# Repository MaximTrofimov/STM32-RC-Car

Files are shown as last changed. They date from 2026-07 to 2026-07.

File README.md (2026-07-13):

# STM32-RC-Car
RC car with manual and autonomous modes, dual STM32 wireless communication (remote and car PCBs).

## Demo Videos

**Manual Mode**

manual

**Autonomous Mode**

autonomous

## Photos

**RC Car and Remote**



**Remote and Car PCBs**



## Overview
- Designed two custom PCBs (remote and car) for a wirelessly-controlled RC car
- Implemented wireless communication between two STM32 microcontrollers using embedded firmware (HAL library)
- Developed manual and autonomous modes

## Hardware
- STM32F446RE (x2 - one in car, one in remote)
- NucleoF446RE (x2 - prototyping)
- NRF24L01+PA+LNA wireless transceiver modules (x2 - one for car, one for remote)
- HC-SR04 ultrasonic sensor (x3 - front, left, right)
- SG90 servo motor (steering)
- TB6612FNG dual H-bridge motor driver (RWD)
- TT dual DC motor 3-6V (x2)
- KY-023 dual-axis analog joystick (remote)
- Custom PCBs (x2 - one for car, one for remote)
- 2S Lipo battery (car)
- 1s Li Ion battery (remote)

## Repo Structure
```
Firmware/
  car_mcu/       - STM32 embedded firmware for the car MCU
  remote_mcu/    - STM32 embedded firmware for the remote MCU
Hardware/
  car_pcb/       - Car PCB, schematic, BOM
  remote_pcb/    - Remote PCB, schematic, BOM
Mechanical/       - Wheels and steering servo enclosure CAD files (STEP)
```

## How It Works

**Manual Mode:**
The X and Y coordinates of the joystick position are read into a two variable array, VR. The array is then transmitted alongside each packet using the remote PCB's NRF24L01 module, and received at the car PCB's NRF24L01 module. The DC Motors are controlled using the TB6612FNG where a maximum joystick value results in fully duty cycle, a neutral results in zero duty cycle, and a minimum results in maximum duty cycle spinning the motors the other way. The SG90 steering is controlled via a timer for PWM. If the joystick is extended to the far right or far left, the NRF24L01 sends a larger joystick value and therefore the pulse is set to high for longer. Both throttle and steering respond to the specific displacement of the joystick from its absolute center, giving it the ability to control speed, and steering degree. The firmware dictates what part of the packet is responsible for motors, what part for the steering angle, and what part for the mode, which is triggered via an interrupt. 

**Autonomous Mode:**
If the joystick button is pressed, the mode is toggled to autonomous. Motors begin by running on half duty cycle and steering is set to a constant of about 20 degrees. The front, left, and right ultrasonic sensors notify the microcontroller when an obstacle is a certain distance away. Once this happens the car stops, checks its sides, goes back, and turns to the side where there is more free space. 

## Firmware Configuration

**Car MCU**
<p float="left">
  
  
</p>

**Remote MCU**
<p float="left">
  
  
</p>

## PCB Design

**Car PCB**
<p float="left">
  
  
</p>

**Remote PCB**
<p float="left">
  
  
</p>

## Breadboard Prototyping

  

## Power

**Car PCB**
- 2S Lipo -> 3.3V (500 mA rating, STM32, NRF24L01, TB6612FNG logic): TPS62152RGTR, reference schematic on Texas Instruments Power Designer.
- 2S Lipo -> 5V (2A rating, TB6612FNG motor power, SG90, HCSR04): TPS82130SILR, reference schematic on Texas Instruments Power Designer.

**Remote PCB**
- 1S Li-Ion -> 3.3V (600 mA rating, STM32, KY-023, NRF24L01): AP2112K-3.3TRG1, reference schematic on datasheet. Used LDO due to lower voltage difference. 

## Credits
- Shawn Hymel STM32 Tutorial Series [https://www.youtube.com/watch?v=hyZS2p1tW-g&list=PLEBQazB0HUyRYuzfi4clXsKUSgorErmBv]
- Phil's Lab KiCad Tutorial [https://www.youtube.com/watch?v=aVUqaB0IMh4]
- NRF24L01 Tutorial Series [https://www.youtube.com/watch?v=mB7LsiscM78&t=996s]
- HCSR04 Tutorial Article [https://controllerstech.com/hcsr04-ultrasonic-sensor-and-stm32/]
- SG90 Tutorial Article [https://controllerstech.com/servo-motor-with-stm32/]
- TB6612FNG Tutorial Video [https://www.youtube.com/watch?v=zWYYvtU8Wt4]
- Joystick Module Tutorial Article [https://controllerstech.com/joystick-and-stm32/]
- Texas Instruments 2S Lipo -> 3.3V Buck Converter Circuit [https://webench.ti.com/power-designer/switching-regulator/customize/5?noparams=0]
- Texas Instruments 2S Lipo -> 5V Buck Converter Circuit [https://webench.ti.com/power-designer/switching-regulator/customize/6?noparams=0]

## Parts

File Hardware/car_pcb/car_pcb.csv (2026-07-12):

Designator | Qty | Comment | DNP | Exclude from BOM | Exclude from Board | Footprint | Datasheet | LCSC Part #
C1,C2,C3,C4,C5,C9,C11,C12,C15 | 9 | 100n |  |  |  | Capacitor_SMD:C_0805_2012Metric |  | C49678
C6,C14,C18,C21,C24 | 5 | 10u |  |  |  | Capacitor_SMD:C_0805_2012Metric |  | C15850
C7 | 1 | 10n |  |  |  | Capacitor_SMD:C_0805_2012Metric |  | C1710
C8 | 1 | 1u |  |  |  | Capacitor_SMD:C_0805_2012Metric |  | C28323
C10 | 1 | 4.7u |  |  |  | Capacitor_SMD:C_0805_2012Metric |  | C1779
C19 | 1 | 390p |  |  |  | Capacitor_SMD:C_0805_2012Metric |  | C1741
C20 | 1 | 22u |  |  |  | Capacitor_SMD:C_0805_2012Metric |  | C45783
C22 | 1 | 430p |  |  |  | Capacitor_SMD:C_0805_2012Metric |  | C67898
L1 | 1 | 2.2u |  |  |  | VLS3012CX-2R2M-1:IND_VLS3012CX-2R2M-1 |  | C2683174
R1 | 1 | 10k |  |  |  | Resistor_SMD:R_0805_2012Metric |  | C176201
R2,R4,R6 | 3 | 1k |  |  |  | Resistor_SMD:R_0805_2012Metric |  | C17513
R3,R5,R7 | 3 | 2k |  |  |  | Resistor_SMD:R_0805_2012Metric |  | C17604
R8,R9,R11 | 3 | 100k |  |  |  | Resistor_SMD:R_0805_2012Metric |  | C25611
R10 | 1 | 523k |  |  |  | Resistor_SMD:R_0805_2012Metric |  | C17742
U1 | 1 | STM32F446RET6 |  |  |  | Package_QFP:LQFP-64_10x10mm_P0.5mm | https://www.st.com/resource/en/datasheet/stm32f446re.pdf | C69336
U2 | 1 | TPS62152 3.3V |  |  |  | Package_DFN_QFN:VQFN-16-1EP_3x3mm_P0.5mm_EP1.68x1.68mm_ThermalVias | http://www.ti.com/lit/ds/symlink/TPS62150.pdf | C2070611
U3 | 1 | TPS82130 5V |  |  |  | Package_LGA:Texas_SIL0008D_MicroSiP-8-1EP_2.8x3mm_P0.65mm_EP1.1x1.9mm_ThermalVias | http://www.ti.com/lit/ds/symlink/tps82130.pdf | C473914

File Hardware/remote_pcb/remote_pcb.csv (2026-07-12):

Reference | Qty | Value | DNP | Exclude from BOM | Exclude from Board | Footprint | Datasheet | LCSC
C1 | 1 | 10u |  |  |  | Capacitor_SMD:C_0805_2012Metric |  | C15850
C2,C3,C4,C5,C6,C9,C13 | 7 | 100n |  |  |  | Capacitor_SMD:C_0805_2012Metric |  | C49678
C7 | 1 | 10n |  |  |  | Capacitor_SMD:C_0805_2012Metric |  | C1710
C8,C11,C12,C15 | 4 | 1u |  |  |  | Capacitor_SMD:C_0805_2012Metric |  | C28323
C10 | 1 | 4.7u |  |  |  | Capacitor_SMD:C_0805_2012Metric |  | C1779
FB1 | 1 | 120R |  |  |  | Inductor_SMD:L_0805_2012Metric |  | C79382
R1,R2 | 2 | 10k |  |  |  | Resistor_SMD:R_0805_2012Metric |  | C176201
U1 | 1 | STM32F446RET6 |  |  |  | Package_QFP:LQFP-64_10x10mm_P0.5mm | https://www.st.com/resource/en/datasheet/stm32f446re.pdf | C69336
U2 | 1 | AP2112K-3.3 |  |  |  | Package_TO_SOT_SMD:SOT-23-5 | https://www.diodes.com/assets/Datasheets/AP2112.pdf | C51118

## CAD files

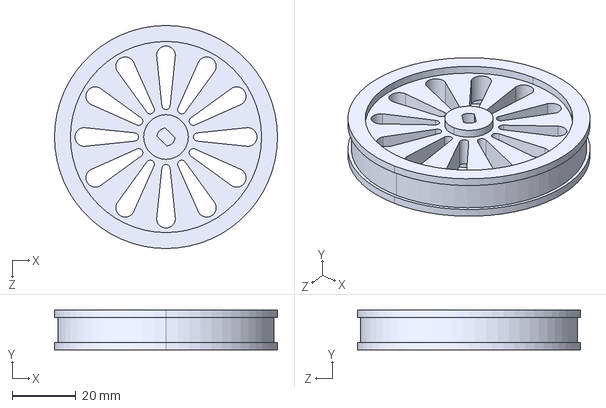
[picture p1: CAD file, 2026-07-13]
Mechanical/RC_Car_Wheel_Rear.STEP
70.0 x 12.5 x 70.0 mm

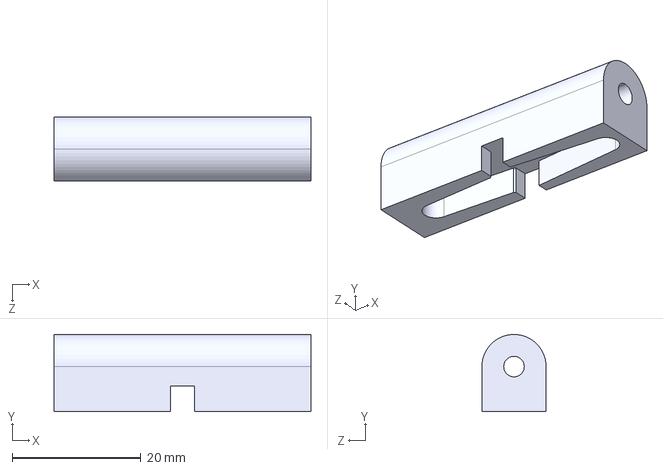
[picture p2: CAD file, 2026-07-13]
Mechanical/Servo_Blade_Enclosure.STEP
40.0 x 12.0 x 10.0 mm

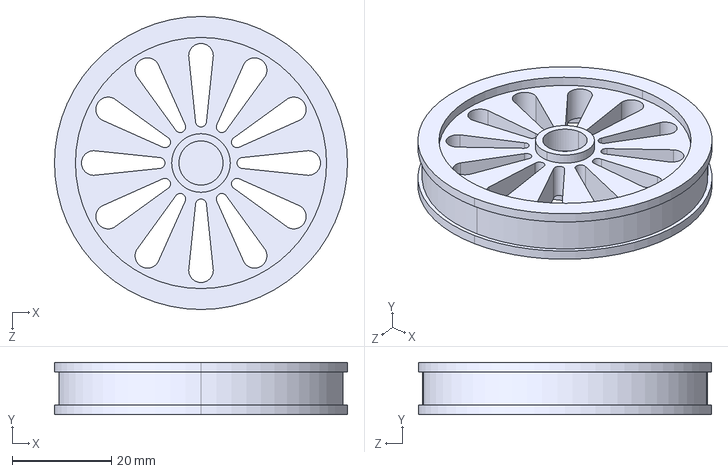
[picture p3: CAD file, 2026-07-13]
Mechanical/RC_Car_Wheel_Front_8.9d.STEP
59.0 x 10.5 x 59.0 mm

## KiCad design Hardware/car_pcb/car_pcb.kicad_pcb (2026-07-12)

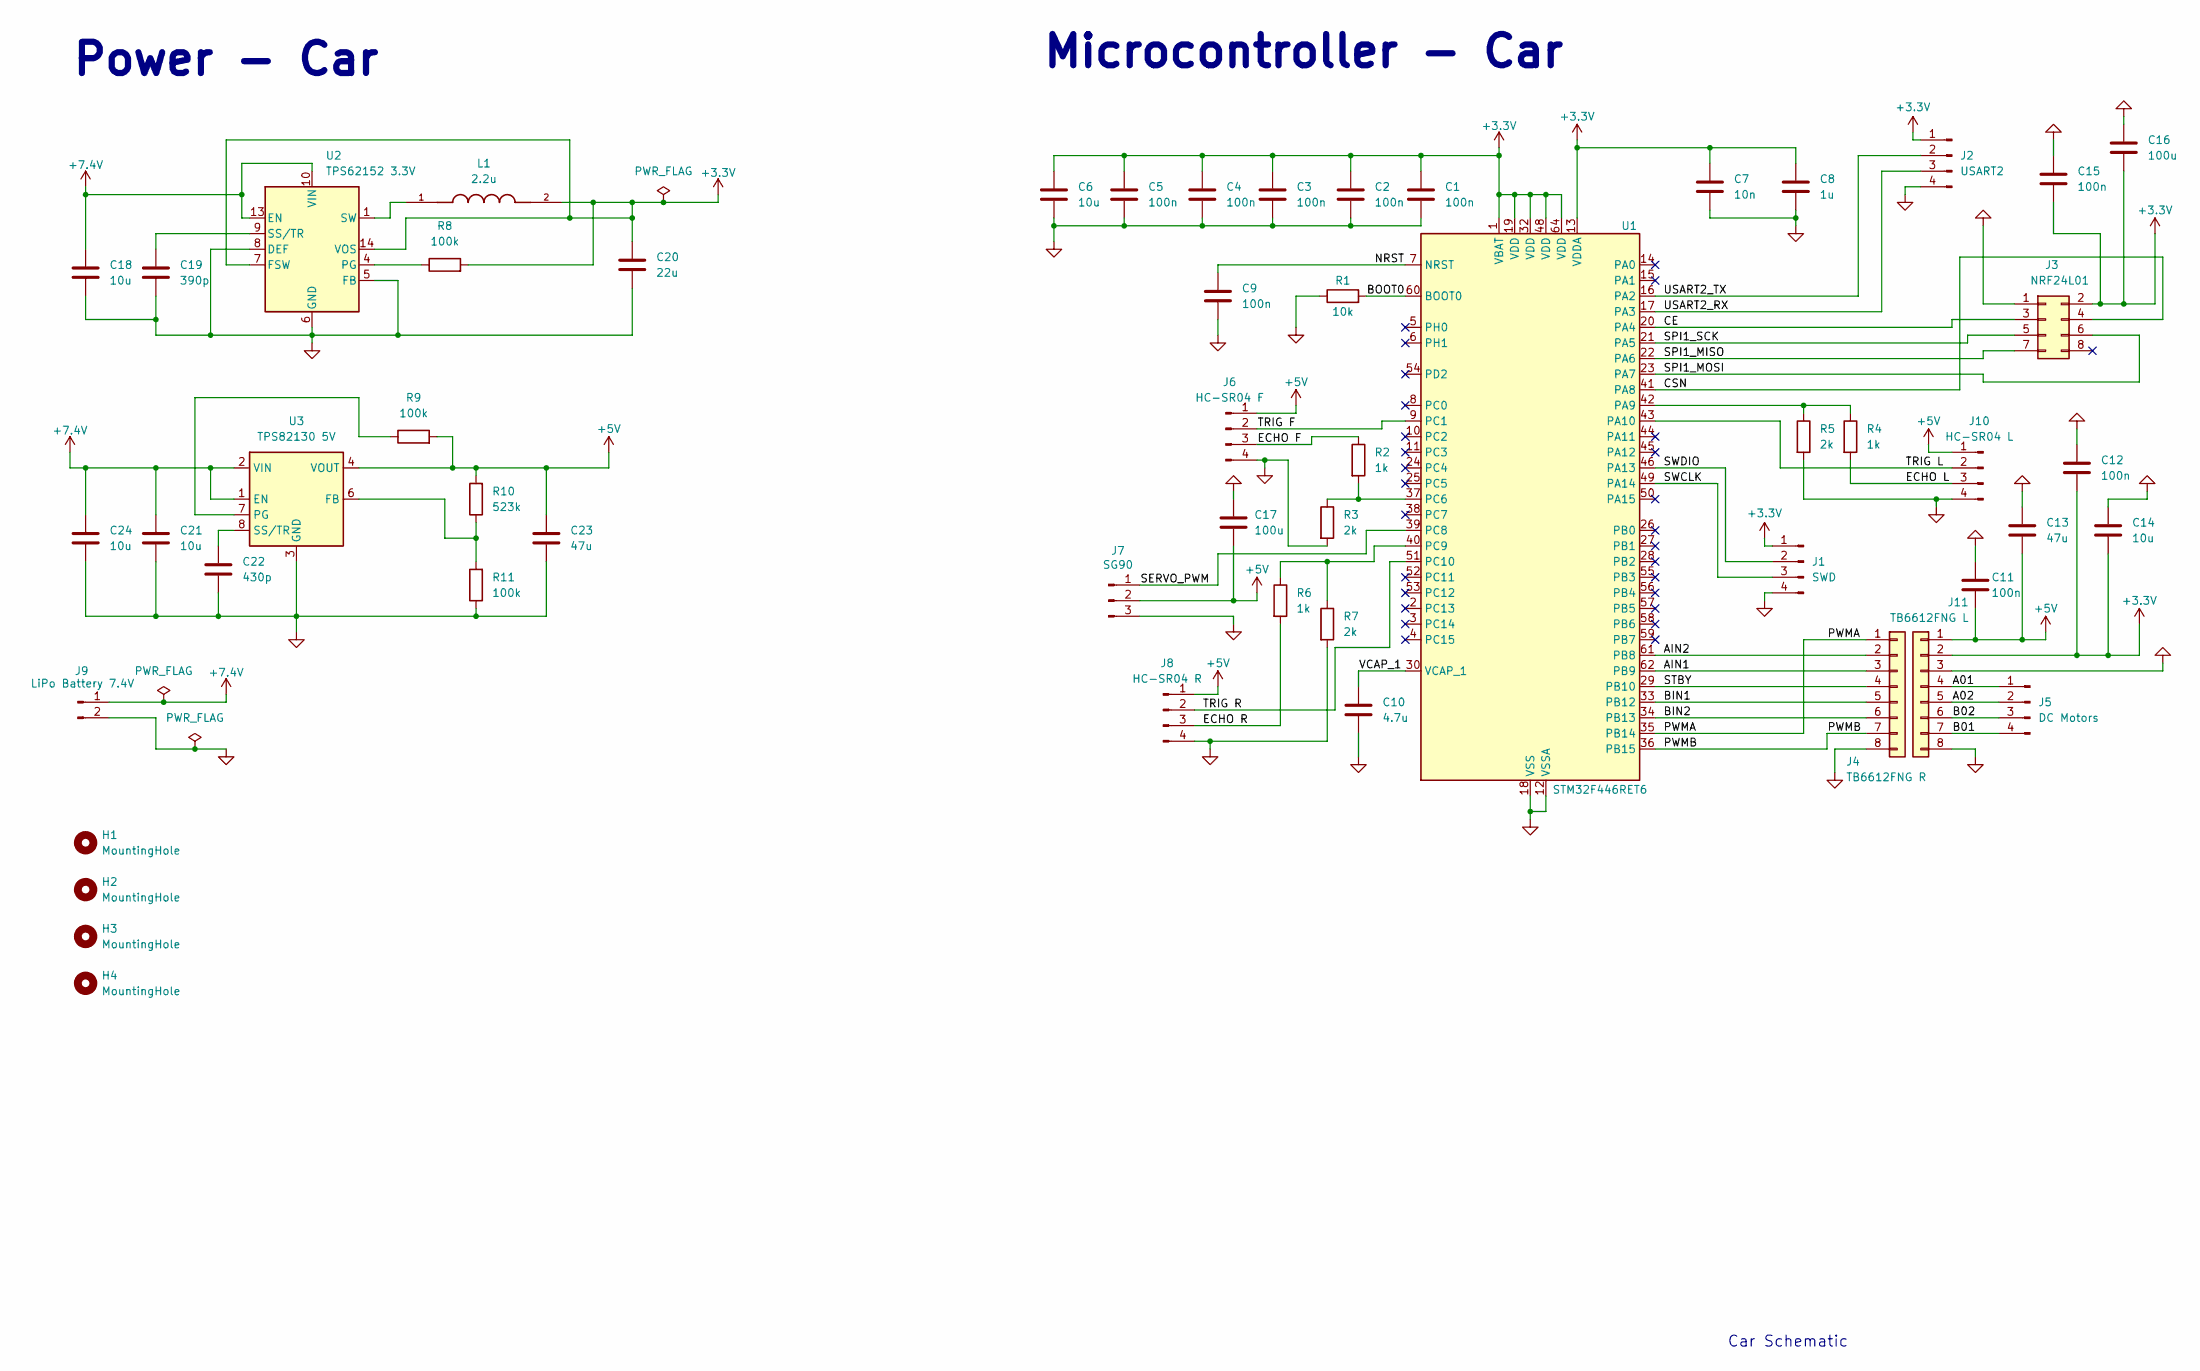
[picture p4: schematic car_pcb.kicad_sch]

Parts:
C1, C2, C3, C4, C5, C9, C11, C12, C15: 100n; C_0805_2012Metric; LCSC C49678
C6, C14, C18, C21, C24: 10u; C_0805_2012Metric; LCSC C15850
C7: 10n; C_0805_2012Metric; LCSC C1710
C8: 1u; C_0805_2012Metric; LCSC C28323
C10: 4.7u; C_0805_2012Metric; LCSC C1779
C13, C23: 47u; C_Radial_D5.0mm_H11.0mm_P2.00mm
C16, C17: 100u; C_Radial_D5.0mm_H11.0mm_P2.00mm
C19: 390p; C_0805_2012Metric; LCSC C1741
C20: 22u; C_0805_2012Metric; LCSC C45783
C22: 430p; C_0805_2012Metric; LCSC C67898
H1, H2, H3, H4: MountingHole; MountingHole_2.2mm_M2
J1: SWD; PinHeader_1x04_P2.54mm_Vertical
J2: USART2; PinHeader_1x04_P2.54mm_Vertical
J3: NRF24L01; PinHeader_2x04_P2.54mm_Vertical
J4: TB6612FNG R; PinHeader_1x08_P2.54mm_Vertical
J5: DC Motors; PinHeader_1x04_P2.54mm_Vertical
J6: HC-SR04 F; PinHeader_1x04_P2.54mm_Vertical
J7: SG90; PinHeader_1x03_P2.54mm_Vertical
J8: HC-SR04 R; PinHeader_1x04_P2.54mm_Vertical
J9: LiPo Battery 7.4V; PinHeader_1x02_P2.54mm_Vertical
J10: HC-SR04 L; PinHeader_1x04_P2.54mm_Vertical
J11: TB6612FNG L; PinHeader_1x08_P2.54mm_Vertical
L1: 2.2u; IND_VLS3012CX-2R2M-1; PARTREV N/A; DigiKey_Part_Number 445-180922-1-ND
R1: 10k; R_0805_2012Metric; LCSC C176201
R2, R4, R6: 1k; R_0805_2012Metric; LCSC C17513
R3, R5, R7: 2k; R_0805_2012Metric; LCSC C17604
R8, R9, R11: 100k; R_0805_2012Metric; LCSC C25611
R10: 523k; R_0805_2012Metric; LCSC C17742
U1: STM32F446RET6; LQFP-64_10x10mm_P0.5mm; LCSC C69336
U2: TPS62152 3.3V; VQFN-16-1EP_3x3mm_P0.5mm_EP1.68x1.68mm_ThermalVias; LCSC C2070611
U3: TPS82130 5V; Texas_SIL0008D_MicroSiP-8-1EP_2.8x3mm_P0.65mm_EP1.1x1.9mm_T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; LCSC C473914

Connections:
+3.3V: C1.1, C2.1, C3.1, C4.1, C5.1, C6.1, C7.1, C8.1, C12.2, C14.2, C15.2, C16.2, C20.1, J1.1, J2.1, J3.2, J11.2, L1.2, R8.2, U1.1 (VBAT), U1.13 (VDDA), U1.19 (VDD), U1.32 (VDD), U1.48 (VDD), U1.64 (VDD), U2.7 (FSW), U2.14 (VOS); also elsewhere on the board
+5V: C11.2, C13.2, C17.2, C23.1, J6.1, J7.2, J8.1, J10.1, J11.1, R9.2, R10.2, U3.4 (VOUT), U3.5 (VOUT); also elsewhere on the board
+7.4V: C18.1, C21.1, C24.1, J9.1, U2.10 (VIN), U2.11 (VIN), U2.12 (VIN), U2.13 (EN), U3.1 (EN), U3.2 (VIN)
/A01: J5.1, J11.4; also elsewhere on the board
/A02: J5.2, J11.5; also elsewhere on the board
/AIN1: J4.3, U1.62 (PB9)
/AIN2: J4.2, U1.61 (PB8)
/B01: J5.4, J11.7; also elsewhere on the board
/B02: J5.3, J11.6; also elsewhere on the board
/BIN1: J4.5, U1.33 (PB12)
/BIN2: J4.6, U1.34 (PB13)
/BOOT0: R1.2, U1.60 (BOOT0)
/CE: J3.3, U1.20 (PA4)
/CSN: J3.4, U1.41 (PA8)
/ECHO F: J6.3, R2.1
/ECHO L: J10.3, R4.2; also elsewhere on the board
/ECHO R: J8.3, R6.2; also elsewhere on the board
/NRST: C9.1, U1.7 (NRST)
/PWMA: J4.1, U1.35 (PB14)
/PWMB: J4.7, U1.36 (PB15)
/SERVO_PWM: J7.1, U1.39 (PC8)
/SPI1_MISO: J3.7, U1.22 (PA6)
/SPI1_MOSI: J3.6, U1.23 (PA7)
/SPI1_SCK: J3.5, U1.21 (PA5)
/STBY: J4.4, U1.29 (PB10)
/SWCLK: J1.3, U1.49 (PA14)
/SWDIO: J1.2, U1.46 (PA13)
/TRIG F: J6.2, U1.9 (PC1)
/TRIG L: J10.2, U1.43 (PA10); also elsewhere on the board
/TRIG R: J8.2, U1.51 (PC10); also elsewhere on the board
/USART2_RX: J2.3, U1.17 (PA3)
/USART2_TX: J2.2, U1.16 (PA2)
/VCAP_1: C10.1, U1.30 (VCAP_1)
GND: C1.2, C2.2, C3.2, C4.2, C5.2, C6.2, C7.2, C8.2, C9.2, C10.2, C11.1, C12.1, C13.1, C14.1, C15.1, C16.1, C17.1, C18.2, C19.2, C20.2, C21.2, C22.2, C23.2, C24.2, J1.4, J2.4, J3.1, J4.8, J6.4, J7.3, J8.4, J9.2, J10.4, J11.3, J11.8, R1.1, R3.2, R5.2, R7.2, R11.1, U1.12 (VSSA), U1.18 (VSS), U1.31 (VSS), U1.47 (VSS), U1.63 (VSS), U2.5 (FB), U2.6 (GND), U2.8 (DEF), U2.15 (GND), U2.16 (GND), U2.17 (GND), U3.3 (GND), U3.9 (GND); also elsewhere on the board
unnamed: L1.1, U2.1 (SW), U2.2 (SW), U2.3 (SW)
unnamed: R4.1, R5.1, U1.42 (PA9)
unnamed: R2.2, R3.1, U1.37 (PC6)
unnamed: R6.1, R7.1, U1.40 (PC9)
unnamed: R8.1, U2.4 (PG)
unnamed: C19.1, U2.9 (SS/TR)
unnamed: R10.1, R11.2, U3.6 (FB)
unnamed: R9.1, U3.7 (PG)
unnamed: C22.1, U3.8 (SS/TR)

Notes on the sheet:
Microcontroller - Car
Car Schematic
Power - Car

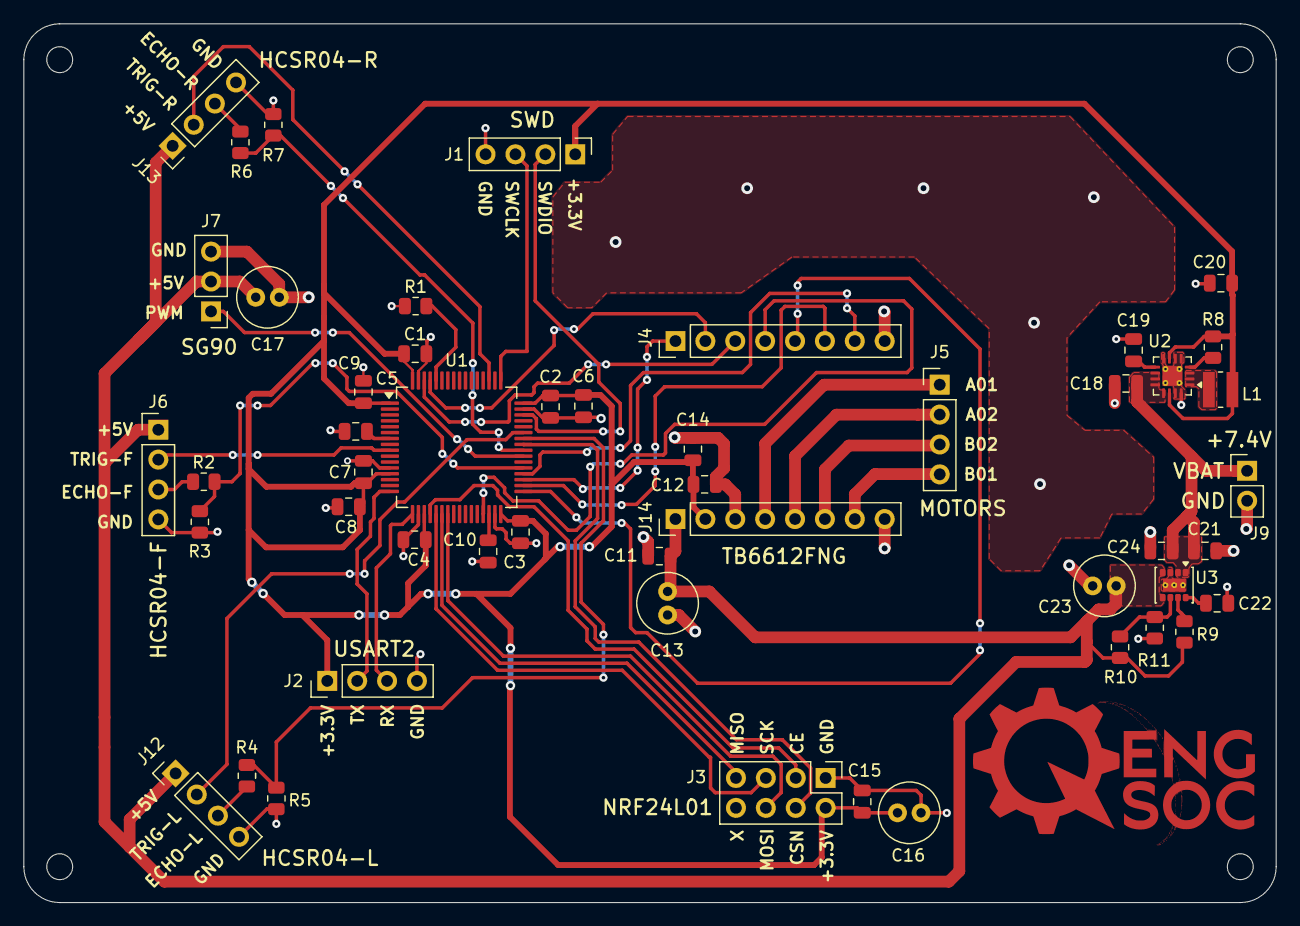
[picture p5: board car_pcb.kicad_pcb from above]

Board: 2 copper layers, 106.4 x 74.7 mm, 54 parts (0 on the bottom side), 43 nets.

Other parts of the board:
J12: HC-SR04 L; PinHeader_1x04_P2.54mm_Vertical
J13: HC-SR04 R; PinHeader_1x04_P2.54mm_Vertical
J14: TB6612FNG L; PinHeader_1x08_P2.54mm_Vertical

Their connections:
+3.3V: J14.2; also elsewhere on the board
+5V: J12.1, J13.1, J14.1; also elsewhere on the board
/A01: J14.4; also elsewhere on the board
/A02: J14.5; also elsewhere on the board
/B01: J14.7; also elsewhere on the board
/B02: J14.6; also elsewhere on the board
/ECHO L: J12.3; also elsewhere on the board
/ECHO R: J13.3; also elsewhere on the board
/TRIG L: J12.2; also elsewhere on the board
/TRIG R: J13.2; also elsewhere on the board
GND: J12.4, J13.4, J14.3, J14.8; also elsewhere on the board

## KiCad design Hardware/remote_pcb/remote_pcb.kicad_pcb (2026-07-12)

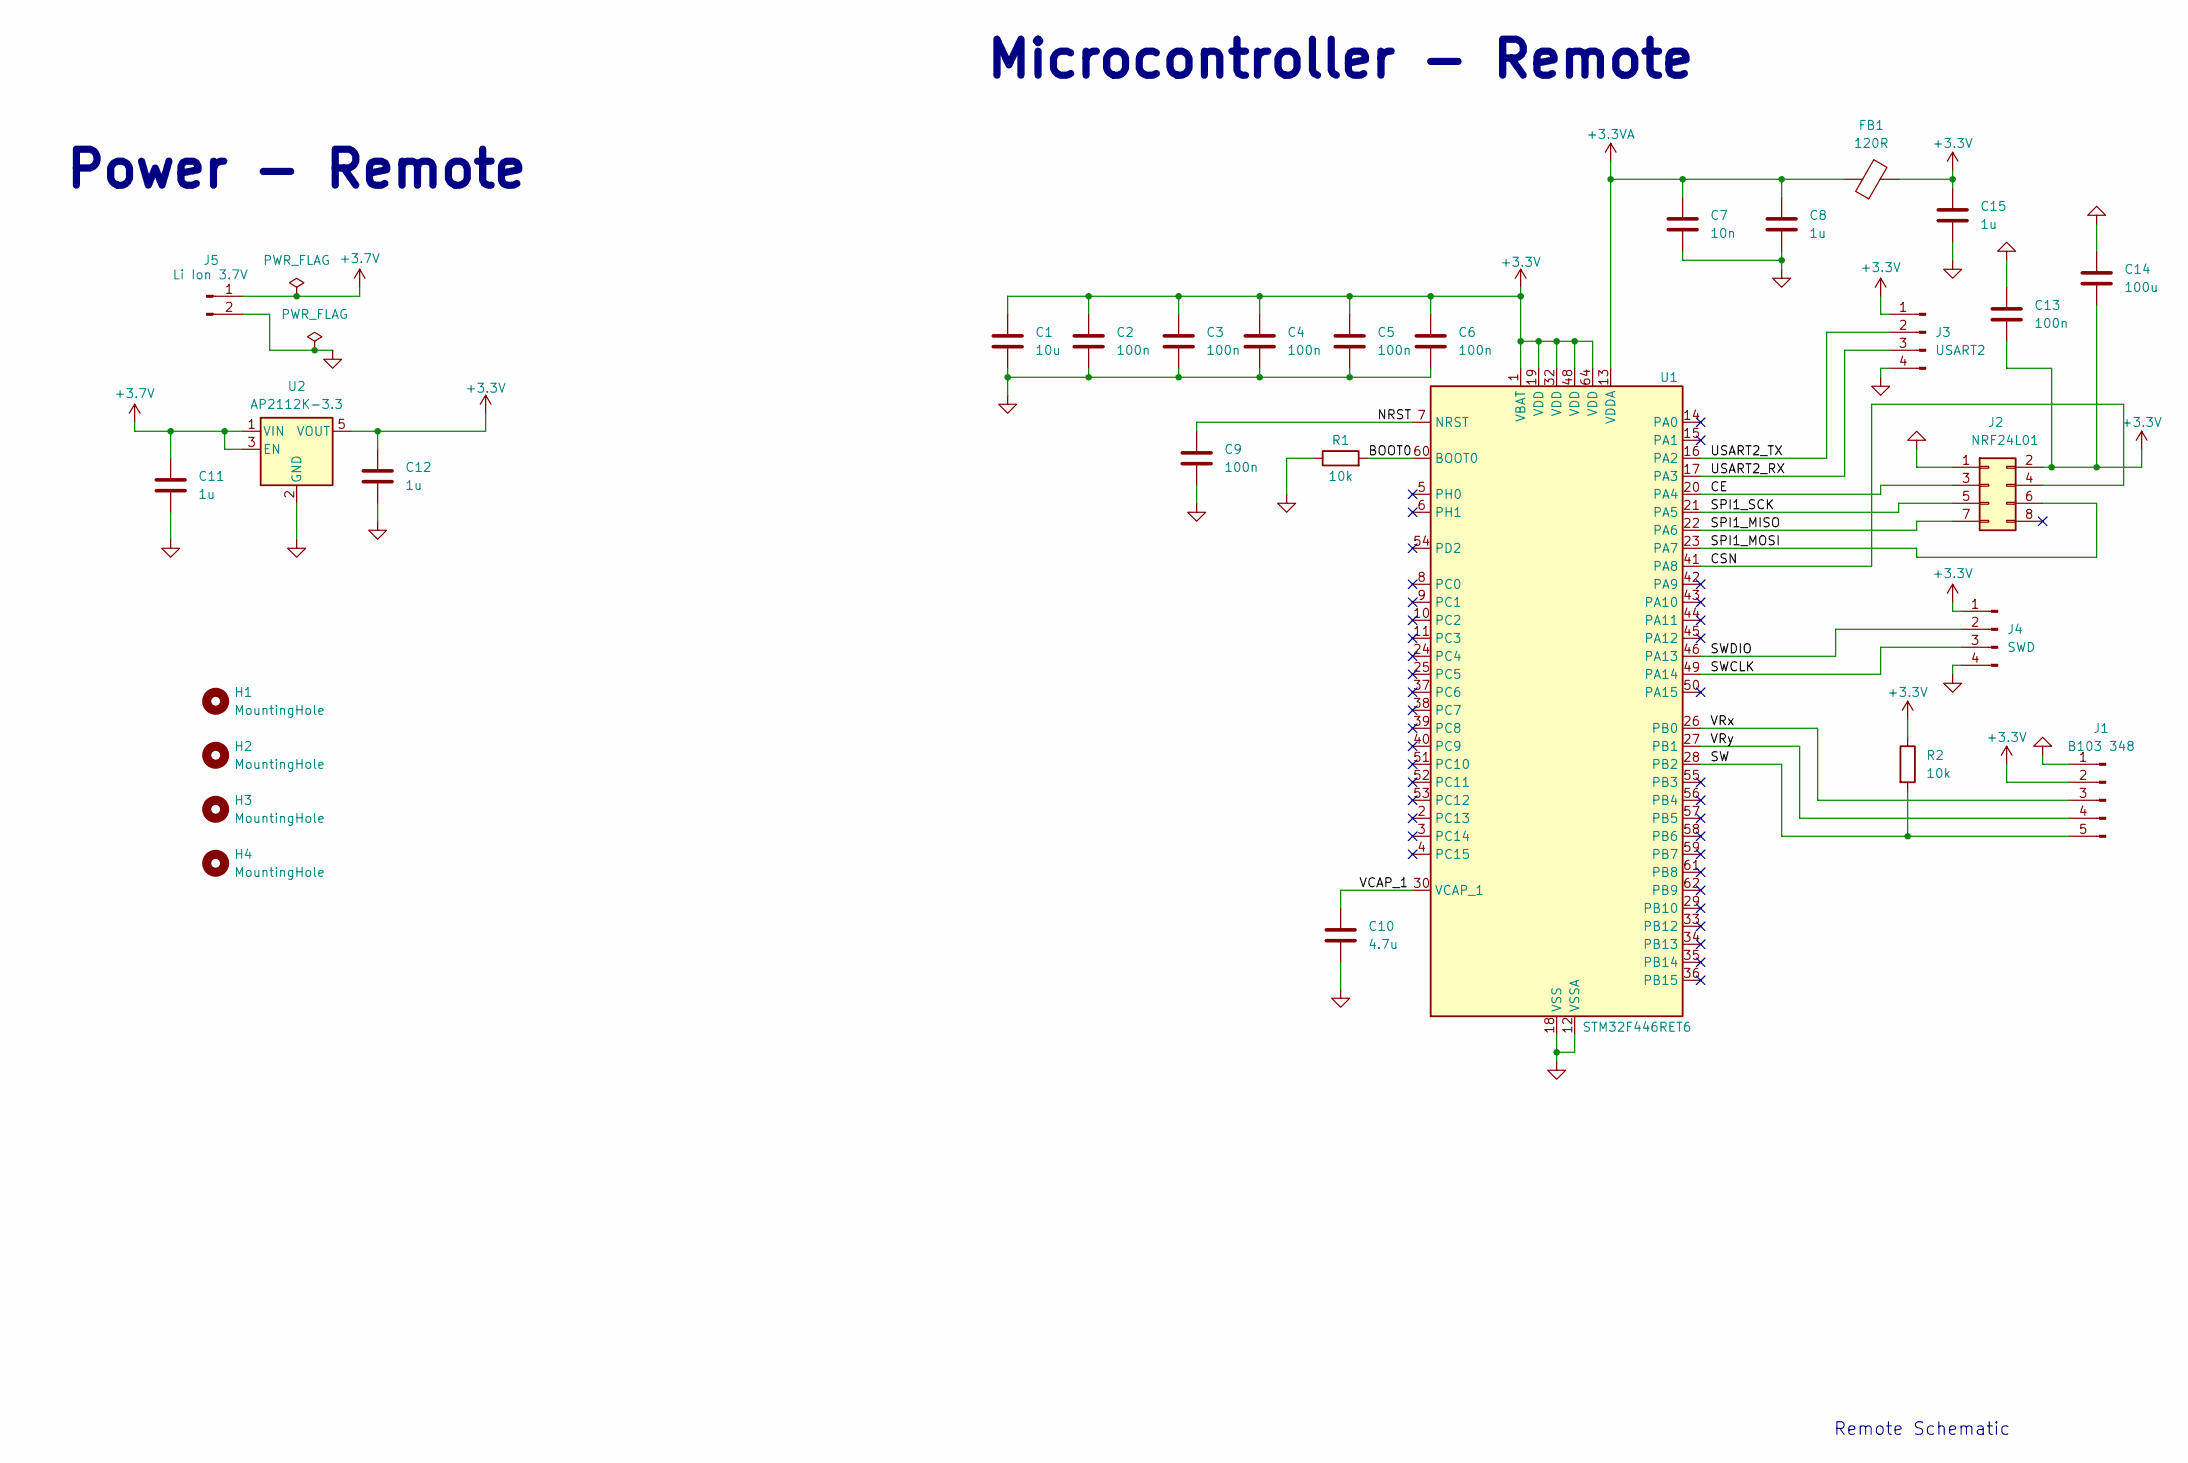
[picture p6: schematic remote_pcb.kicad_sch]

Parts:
C1: 10u; C_0805_2012Metric; LCSC C15850
C2, C3, C4, C5, C6, C9, C13: 100n; C_0805_2012Metric; LCSC C49678
C7: 10n; C_0805_2012Metric; LCSC C1710
C8, C11, C12, C15: 1u; C_0805_2012Metric; LCSC C28323
C10: 4.7u; C_0805_2012Metric; LCSC C1779
C14: 100u; C_Radial_D5.0mm_H11.0mm_P2.00mm
FB1: 120R; L_0805_2012Metric; LCSC C79382
H1, H2, H3, H4: MountingHole; MountingHole_2.2mm_M2
J1: B103 348; PinHeader_1x05_P2.54mm_Vertical
J2: NRF24L01; PinHeader_2x04_P2.54mm_Vertical
J3: USART2; PinHeader_1x04_P2.54mm_Vertical
J4: SWD; PinHeader_1x04_P2.54mm_Vertical
J5: Li Ion 3.7V; JST_XH_B2B-XH-A_1x02_P2.50mm_Vertical
R1, R2: 10k; R_0805_2012Metric; LCSC C176201
U1: STM32F446RET6; LQFP-64_10x10mm_P0.5mm; LCSC C69336
U2: AP2112K-3.3; SOT-23-5; LCSC C51118

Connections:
+3.3V: C1.1, C2.1, C3.1, C4.1, C5.1, C6.1, C12.1, C13.2, C14.2, C15.1, FB1.2, J1.2, J2.2, J3.1, J4.1, R2.1, U1.1 (VBAT), U1.19 (VDD), U1.32 (VDD), U1.48 (VDD), U1.64 (VDD), U2.5 (VOUT)
+3.3VA: C7.1, C8.1, FB1.1, U1.13 (VDDA)
+3.7V: C11.1, J5.1, U2.1 (VIN), U2.3 (EN)
/BOOT0: R1.2, U1.60 (BOOT0)
/CE: J2.3, U1.20 (PA4)
/CSN: J2.4, U1.41 (PA8)
/NRST: C9.1, U1.7 (NRST)
/SPI1_MISO: J2.7, U1.22 (PA6)
/SPI1_MOSI: J2.6, U1.23 (PA7)
/SPI1_SCK: J2.5, U1.21 (PA5)
/SW: J1.5, R2.2, U1.28 (PB2)
/SWCLK: J4.3, U1.49 (PA14)
/SWDIO: J4.2, U1.46 (PA13)
/USART2_RX: J3.3, U1.17 (PA3)
/USART2_TX: J3.2, U1.16 (PA2)
/VCAP_1: C10.1, U1.30 (VCAP_1)
/VRx: J1.3, U1.26 (PB0)
/VRy: J1.4, U1.27 (PB1)
GND: C1.2, C2.2, C3.2, C4.2, C5.2, C6.2, C7.2, C8.2, C9.2, C10.2, C11.2, C12.2, C13.1, C14.1, C15.2, J1.1, J2.1, J3.4, J4.4, J5.2, R1.1, U1.12 (VSSA), U1.18 (VSS), U1.31 (VSS), U1.47 (VSS), U1.63 (VSS), U2.2 (GND)

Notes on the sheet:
Power - Remote
Microcontroller - Remote
Remote Schematic

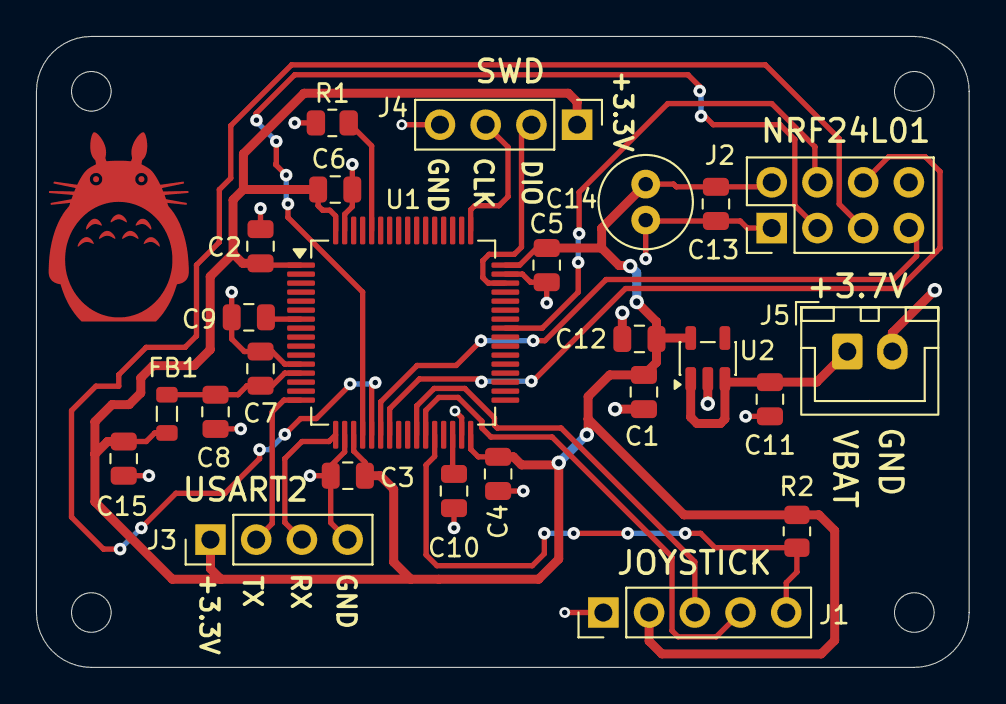
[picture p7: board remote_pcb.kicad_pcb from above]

Board: 2 copper layers, 51.8 x 35.1 mm, 29 parts (0 on the bottom side), 19 nets.

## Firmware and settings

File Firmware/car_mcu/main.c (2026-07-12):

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
/* Includes ------------------------------------------------------------------*/
#include "main.h"

/* USER CODE BEGIN Includes */
#include "string.h"
#include <stdio.h>
#include "NRF24L01.h"
#include "HCSR04.h"
#include "SG90.h"
#include "TB6612FNG.h"
#include "autonomous.h"
/* USER CODE END Includes */

/* USER CODE BEGIN PD */
#define TRIG_PORT_F GPIOC
#define TRIG_PIN_F GPIO_PIN_1

#define TRIG_PORT_L GPIOA
#define TRIG_PIN_L GPIO_PIN_10

#define TRIG_PORT_R GPIOC
#define TRIG_PIN_R GPIO_PIN_10

/* USER CODE END PD */

SPI_HandleTypeDef hspi1;

TIM_HandleTypeDef htim1;
TIM_HandleTypeDef htim2;
TIM_HandleTypeDef htim3;
TIM_HandleTypeDef htim8;
TIM_HandleTypeDef htim12;

UART_HandleTypeDef huart2;

void SystemClock_Config(void);
static void MX_GPIO_Init(void);
static void MX_SPI1_Init(void);
static void MX_TIM12_Init(void);
static void MX_TIM3_Init(void);
static void MX_TIM8_Init(void);
static void MX_USART2_UART_Init(void);
static void MX_TIM1_Init(void);
static void MX_TIM2_Init(void);
/* USER CODE BEGIN 0 */
volatile float distance_front = 1000.0;
volatile float distance_right = 1000.0;
volatile float distance_left = 1000.0;

typedef struct __attribute__((packed)) {
	uint8_t mode;
	uint16_t steering;
	uint16_t throttle;
	uint8_t reserved[27];
} ControlPacket;
char buf[20];

volatile uint32_t IC_Val1_F = 0;
volatile uint32_t IC_Val2_F = 0;
volatile uint32_t Difference_F = 0;
volatile uint8_t Is_First_Captured_F = 0;

volatile uint32_t IC_Val1_R = 0;
volatile uint32_t IC_Val2_R = 0;
volatile uint32_t Difference_R = 0;
volatile uint8_t Is_First_Captured_R = 0;

volatile uint32_t IC_Val1_L = 0;
volatile uint32_t IC_Val2_L = 0;
volatile uint32_t Difference_L = 0;
volatile uint8_t Is_First_Captured_L = 0;

uint8_t RxAddress[] = { 0xEE, 0xDD, 0xCC, 0xBB, 0xAA }; // address of the receiver data is sent to
char remoteBuffer[120];

/* USER CODE END 0 */

/**
 * @brief  The application entry point.
 * @retval int
 */
int main(void) {

	/* MCU Configuration--------------------------------------------------------*/

	/* Reset of all peripherals, Initializes the Flash interface and the Systick. */
	HAL_Init();

	/* Configure the system clock */
	SystemClock_Config();

	/* Initialize all configured peripherals */
	MX_GPIO_Init();
	MX_SPI1_Init();
	MX_TIM12_Init();
	MX_TIM3_Init();
	MX_TIM8_Init();
	MX_USART2_UART_Init();
	MX_TIM1_Init();
	MX_TIM2_Init();
	/* USER CODE BEGIN 2 */

	HAL_TIM_Base_Start(&htim2);  // for microsecond delay HCSR04
	HAL_TIM_IC_Start_IT(&htim1, TIM_CHANNEL_2); // for HCSR04 input capture with interrupt
	HAL_TIM_IC_Start_IT(&htim8, TIM_CHANNEL_1); // for HCSR04 input capture with interrupt
	HAL_TIM_IC_Start_IT(&htim8, TIM_CHANNEL_4); // for HCSR04 input capture with interrupt
	HAL_TIM_PWM_Start(&htim3, TIM_CHANNEL_3); // for SG90 PWM
	NRF24_Init();

	HAL_TIM_PWM_Start(&htim12, TIM_CHANNEL_1);
	HAL_TIM_PWM_Start(&htim12, TIM_CHANNEL_2);

	NRF24_RxMode(RxAddress, 10); // both boards must be on the same channel to communicate

	/* USER CODE END 2 */

	/* Infinite loop */
	/* USER CODE BEGIN WHILE */
	while (1) {

		/* USER CODE END WHILE */

		/* USER CODE BEGIN 3 */

		ControlPacket carPacket;

		if (isDataAvailable(1) == 1) {

			NRF24_Receive((uint8_t*) &carPacket);

			Motors(carPacket.throttle);
			Servo(carPacket.steering);
		}
	}

	/* USER CODE END 3 */
}

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


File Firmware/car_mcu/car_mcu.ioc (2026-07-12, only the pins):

Mcu.UserName=STM32F446RETx
PA10.Signal=GPIO_Output
PA13.Signal=SYS_JTMS-SWDIO
PA14.Signal=SYS_JTCK-SWCLK
PA2.Signal=USART2_TX
PA3.Signal=USART2_RX
PA4.GPIO_Label=CE
PA4.Signal=GPIO_Output
PA5.Signal=SPI1_SCK
PA6.Signal=SPI1_MISO
PA7.Signal=SPI1_MOSI
PA8.GPIO_Label=CSN
PA8.Signal=GPIO_Output
PA9.Signal=S_TIM1_CH2
PB10.Signal=GPIO_Output
PB12.Signal=GPIO_Output
PB13.Signal=GPIO_Output
PB14.Signal=S_TIM12_CH1
PB15.Signal=S_TIM12_CH2
PB8.Signal=GPIO_Output
PB9.Signal=GPIO_Output
PC1.Signal=GPIO_Output
PC10.Signal=GPIO_Output
PC6.Signal=S_TIM8_CH1
PC8.Signal=S_TIM3_CH3
PC9.Signal=S_TIM8_CH4

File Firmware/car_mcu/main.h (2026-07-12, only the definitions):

#define CE_Pin GPIO_PIN_4
#define CE_GPIO_Port GPIOA
#define CSN_Pin GPIO_PIN_8
#define CSN_GPIO_Port GPIOA

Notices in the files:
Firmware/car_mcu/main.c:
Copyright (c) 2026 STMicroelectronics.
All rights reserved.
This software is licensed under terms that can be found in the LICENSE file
